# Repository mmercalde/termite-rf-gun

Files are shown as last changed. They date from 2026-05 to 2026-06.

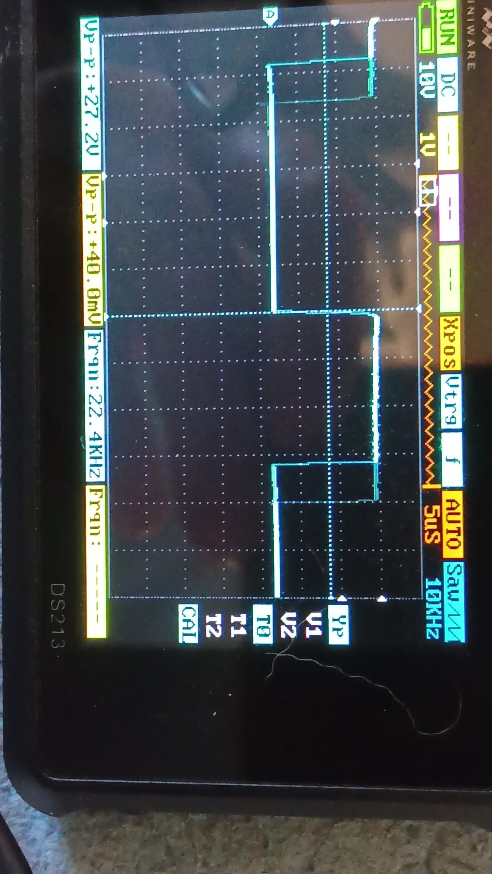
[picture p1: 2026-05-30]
docs/bench_observations/2026-05-30_frankenboard_dry_run_22kHz_DANGER.jpg

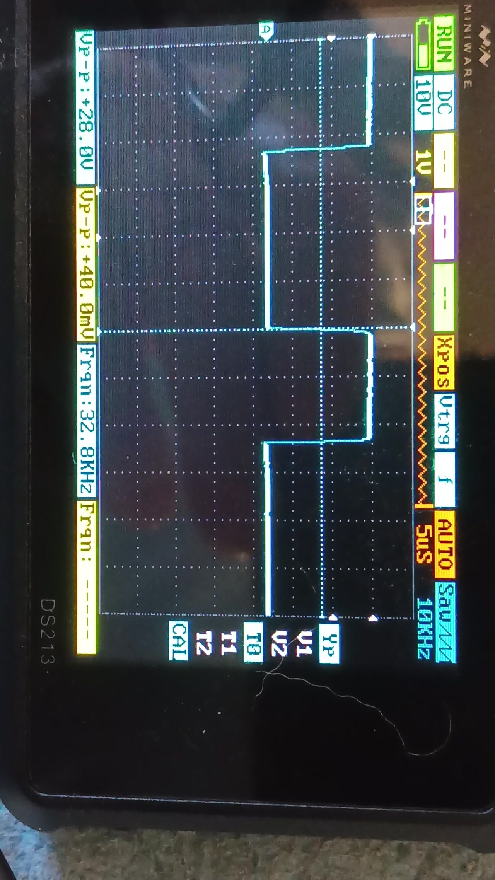
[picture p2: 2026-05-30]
docs/bench_observations/2026-05-30_frankenboard_dry_run_33kHz.jpg

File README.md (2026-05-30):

# termite-rf-gun

ESP32-S3 standalone driver for microwave inverter HV boards, powering an RF
applicator (launcher + copper-lined horn) for **termite control**. Goal: drive
a microwave inverter board with no oven main board (DPC), generating the HV the
magnetron needs, under ESP32 command.

Three inverter boards have been investigated. Status of each is below.

---

## Boards

### 1. Panasonic F606Y8X00AP — SINGLE-IGBT — ✅ SOLVED / PROVEN

The inverter board from a **Panasonic NN-SN778S** (120 V US oven).
Cross-references: replaces **F606Y8M00AP**; ABH-version variant is **F606Y9X90AP**
(this oven is the APH/USA version → F606Y8X00AP). Fits NN-SN7xx-series US ovens.

- **Driver: `panasonic_inverter_esp32s3/`** (tagged `working-standalone`)
- **Method that worked: CAPTURE & REPLICATE.** Built an ESP32 edge-logger
  (`log` mode, GPIO6 via divider off CN701 pin1), captured the real oven's
  command, then replicated it.
- **Measured command (the key result):**
  - **222 Hz** (period 4509 µs)
  - **~85 % HIGH duty**, idles HIGH, ~565–665 µs LOW notch
  - **NO soft-start** — full duty from cycle one; the inverter's own closed-loop
    current regulation handles magnetron inrush internally
  - **More HIGH duty = more power** (`INVERT_CMD=false` confirmed). The old
    "≤43 % duty to start" advice from a video was WRONG — under-driving gave
    "HV but no oscillation."
- Pin 3 (orange) tied to **1k → GND** sufficed on this board.
- **CONFIRMED WORKING** — magnetron oscillated under ESP32 drive.
- This board is borrowed from the kitchen oven. A twin (F606Y8X00AP) is the
  clean known-good path if the dual-IGBT effort stalls: runs on this firmware
  day one, no further tuning.

**Wiring (single-IGBT):**
```
GPIO4 -> CN701 pin1 (YELLOW)  command, push-pull TTL 222Hz/85%
GPIO5 -> CN701 pin3 (ORANGE)  optional 2nd signal (1k->GND also works)
GND   -> CN701 pin2 (BROWN)
GPIO7 <- zero-cross (monitor only)
GPIO6 <- capture tap (divider) for 'log' mode
GPIO1 = BTN ON/OFF ; GPIO2 = BTN power step
```

---

### 2. Panasonic F6645M301GP ("M3GP") — DUAL-IGBT — 🔧 TOPOLOGY PROVEN, TUNING PENDING

Dual-IGBT half-bridge board. **This is a 230–240 V board** (confirmed, see below).
Originally bought (×2) as a replacement for the NN-SN778S — that was a **mistake
on two axes**: wrong part family entirely (F606 vs F6645, single vs dual IGBT)
AND wrong voltage (230 V vs 120 V). Ironically these are the higher-power 240 V
boards that were actually wanted — accidentally the right thing.

- **Driver: `panasonic_dual_igbt_esp32s3/`**
- **Devices (original, both OBSOLETE):** big switch **Toshiba GT50J327**
  (intact); small switch **Toshiba GT35J321** (600 V / 35 A, the one that pops).
  Half-bridge topology.
- **Replacement IGBTs (Infineon TRENCHSTOP RC-H5, designed for inverterized
  microwave ovens / induction cooking, TO-247-3pin, monolithic body diode,
  8–60 kHz switching range):**
  - Big switch position → **IHW40N120R5** (1200 V / 40 A, BV min 1350 V)
  - Small switch position → **IHW30N120R5** (1200 V / 30 A, BV min 1350 V)
  - Voltage headroom on the small switch goes from 600 V → 1200 V, structurally
    eliminating the overvoltage-avalanche failure mode (candidate #3 below).
  - Bought 4× of each from Mouser → 4 rebuilds / tuning-casualty budget.
  - Keep ASYMMETRIC per Panasonic's original design (40 A big + 30 A small).
    Do NOT use 2× 30 A (big switch undersized at 30 A vs. resonant tank current)
    and do not "upgrade" to 2× 40 A on first attempt — it changes dead-time
    margin against shoot-through.
- **Controller IC:** Panasonic **AN47054A** class (undocumented). Runs closed-loop
  off DC-link / resonant-voltage / input-current sensing; generates the
  20–40 kHz IGBT gate switching itself. CN701 takes the LOW-FREQ ~220 Hz command,
  NOT the 20–40 kHz (that's an internal gate-drive frequency — common myth).
- **Resonant cap C703 = WF 395J 250V = 3.9 µF film**, sits IGBT-emitter to
  transformer primary. Measured 3.9 µF out of circuit → GOOD. (A resonant cap
  reads ~0 V at idle whether good or bad — only develops voltage during
  oscillation, so an idle 0 V reading is NOT a fault indicator.)
- Other caps: 505J/250V (~5 µF), WFK 184J/550V (180 nF across IGBT collectors).
  **No bulk electrolytic bus cap** — Panasonic design uses a small/unfiltered
  pulsating rectified rail by design.

**240 V CONFIRMATION (multiple independent sources):**
- Every parts listing cross-refs F6645M301GP to **230 V ovens**: NN-GT548M,
  NN-GD376S/GD576M, NN-GS, NN-K series (EU/Asia/Australia). No US 120 V model.
- Big IGBT GT50J327 = high-voltage Toshiba "J" series (now obsolete; replaced
  with IHW40N120R5 = 1200 V).
- Bridge rectifier = **D20SB80 = 800 V / 560 V RMS / 20 A** — built for a 230 V
  line (RMS ~240 V, peak ~340 V). A 120 V board would use a ~400 V bridge.
- At 120 V input → bus only ~163 V (measured) = half of the ~325–340 V it needs
  → under-voltage → "fires briefly then trips." Explains every earlier symptom.

**RESULT AT 240 V (the breakthrough):**
- Fed proper 240 V from the off-grid solar system (240 V double-breaker).
- Loaded `panasonic_dual_igbt_esp32s3`, typed `on` → **IT OSCILLATED.**
- This proves: 230 V board confirmed, command correct, feedback correct, board
  CAN run standalone on ESP32 drive.
- BUT after ~2–4 s: **POP** — the small IGBT (GT35J321) shorted.

**Why it popped (analysis — NOT simple thermal soak; it only ran 2–4 s on a
large heatsink):** more likely one of:
1. **Shoot-through** — half-bridge dead-time/timing off → both IGBTs briefly on
   → bus short through both → smallest device dies first. (µs-fast.)
2. **Over-current off-resonance** — resonant inverter; if driven off the tank's
   resonant point the IGBT current exceeds rating → fast junction failure.
3. **Overvoltage on the 600 V small IGBT** — at 340 V bus + resonant ringing, a
   transient can push the GT35J321 (only 600 V) past its limit → avalanche.
- All three trace to driving **open-loop** without the full closed-loop
  protection the AN47054A normally applies. The single-IGBT board tolerates
  open-loop because it's simpler; the dual half-bridge has shoot-through as a
  failure mode that only exists with two switches.
- NOTE: the two boards on hand had been **cross-swapped with parts between two
  damaged boards** (one had both IGBTs blown, the other a blown HV diode), so
  the board that popped was a hybrid of uncertain part health → its result is
  not fully trustworthy. → decision: buy NEW known-good boards to tune against.

**STATUS / NEXT (when new boards arrive):**
- Ordered new known-good F6645M301GP boards (AliExpress, "100% test working",
  ~$24.69 ea).
- Before firing a new board: set up a proper TUNING RIG —
  1. **Current limiting on the 240 V feed** (so a bad signal trips, not detonates
     the IGBT) — variac / resistive heater element / fast fuse.
  2. **Scope on the small IGBT gate (and/or its Vce)** — to SEE shoot-through
     (gate overlap) or overvoltage (Vce — with the new IHW30N120R5's 1200 V
     rating this is far less risky than with the original 600 V GT35J321, but
     still scope it) instead of tuning blind.
- Tuning procedure: start `p 40`, short 1–2 s bursts, watch gate scope + input
  current, dial up only when stable. Sweep feedback: try `sig2off` (free-run)
  vs the 110 Hz emulation, vary timing.
- Spares on hand: 4× **IHW30N120R5** (small position) + 4× **IHW40N120R5** (big
  position), Mouser, ~$5/ea. The original Toshiba GT35J321 / GT50J327 are
  obsolete and not worth sourcing — the Infineon RC-H5 parts are the modern
  replacement Infineon themselves market for inverterized microwave ovens.
  Casualties during tuning are expected; replacing one is a 10-min job.
- WHEN REPLACING A POPPED IGBT: also diode-check the partner IGBT AND the
  gate-driver components on that half-bridge leg BEFORE repowering — a shorted
  half-bridge IGBT often takes the driver/partner with it; powering into a
  damaged leg pops the new device instantly.

**Wiring (dual-IGBT):**
```
GPIO4 -> CN701 pin1 (YELLOW)        command, push-pull TTL 222Hz
GPIO5 -> 1k -> CN701 pin3 (ORANGE)  OPEN-DRAIN 110Hz/50% feedback emulation
GND   -> CN701 pin2 (BROWN)
GPIO7 <- zero-cross (monitor only)
```
Pin 3 is an open-collector line the board pulls to 5 V (measured 5 V HIGH on
start). GPIO5 only SINKS / releases (never sources). The 1k series protects the
non-5V-tolerant GPIO when it's released into the board's 5 V pull-up.

Console: `on` `off` `p<10-95>` `f<hz>` `ss <duty> <ms>` `sson` `ssoff`
`sig2on` `sig2off` `log` `logdump` `zc` `status`. Defaults: soft-start 35 %/2 s
→ ramp → 70 %, pin3 feedback ON, 222 Hz.

---

### 3. LG EBR82899411 / EBR82899402 — 🅿️ PARKED (revisit while waiting on dual boards)

Inverter from an **LG MSER2090S NeoChef** (120 VAC / 1200 W, magnetron 2M286-21).
Service manual: `mser2090s.pdf` (P/NO MFL69902612).

- **Architecture (per service manual + bench):** main board sends a command over
  **CN3** → the inverter's LOCAL hot-side MICOM **U1 (Renesas R5F1076C)** runs the
  closed loop and generates the 24–70 kHz IGBT switching itself. Same
  division of labor as the Panasonic (slow command in, fast switching local).
- **BLOCKER:** U1 stays **dead until mains is applied** — its 5 V/15 V bias derives
  from the rectified mains via the on-board regulator (U3). So the command path
  CANNOT be bench-tested on 15 V logic bias alone; U1 isn't running. This is the
  one structural difference from the Panasonic and why the LG is the hardest:
  it needs a **live-mains hot-side bring-up** before the command path is even
  testable, and then still needs a capture of CN3 to learn the command.

**CN3 pinout (bench-confirmed):**
```
Pin1 = U4 LED side via 10k (status opto, not our concern)
Pin2 = U4 LED other side (status, not our concern)
Pin3 = PWM cathode-side via on-board 330R to U2 LED cathode (drive LOW to enable)
Pin4 = PWM anode-side via on-board 330R to U2 LED anode (drive HIGH to enable)
Pin5 = key gap (unpopulated)
Pin6 = GND
Pin7 = +15V input
```
PWM control scheme: hold pin4 at +5 V, PWM pin3 (LOW = LED on = power).
F-11 test (svc man p5-26): CN3 pins 6–7 read OPEN(OL) normally; short = fault
(power-rail check, NOT a comms-pair check).

**Diagnostic IC values (svc man p5-27, ±10 % = OK):**
```
U1 MICOM (R5F1076C) pin2->GND = 15-20k ; pin10->GND = 4.5k
U6 gate driver (2EDL05I06PF, Infineon) = 1.0 Mohm
U7 op-amp (SN358) = 4.5k
U8 dual comparator (KIA393F) = 1.0 Mohm
TH91 thermistor ~20k @ room temp (F-16/17 if bad)
IGBT Q1: ~10k G-E ; C-E diode 0.4-0.6V
Bridge D5: open/short ; HV diodes D8,D9: open/short
```
Components: U1=RL78 MICOM, U2=PWM input opto, U3=onboard 5V reg, U4=status opto,
U6=Infineon half-bridge gate driver, U7=SN358 dual op-amp, U8=KIA393F dual comp,
Q1=IGBT, ZD201=trigger zener, TH91=B/D temp thermistor, D5=bridge, D8/D9=HV doubler.

**Bench results so far:** cold side draws 23 mA at 15 V idle; U3 outputs solid 5 V;
U2 LED conducts (5 mA bump) when pin4→5V AND pin3→GND (PWM input path functional).
U4 LED shows 1.16 V drop at idle (status output active). SPICE note: driving U2
via emitter-follower collapses to ~72 mV; open-collector (pull-up to 5V) gives a
proper 1.6–4.4 V swing, and response is INVERTED (higher duty = lower volts).

**NEXT for LG:** the only way forward is to confirm U1 wakes on mains. Plan:
(1) verify U2 phototransistor side crosses the isolation barrier (LED off vs on);
(2) live-mains hot-side power-up to bring U1 alive (DANGEROUS — mains-referenced
MICOM probing); (3) then capture CN3 during a real start to learn the command.
This is the most dangerous and least-certain path of the three — only worth it
as a "while waiting" exercise, with full mains-safety discipline.

---

## Firmware notes (shared)

- ESP32-S3 Dev Module, Arduino core 2.x/3.x, 4 MB, PSRAM off, USB CDC On Boot.
- Same ESP harness across all builds — only the command wire lands on a different
  connector/pin per board.
- `log` mode = capture an oven's real command on GPIO6 (via divider). This is the
  method that cracked the single-IGBT board and is the intended method for any
  board where a working oven is available to capture from.
- Serial 115200.

## Hard-won lessons

1. **Capture beats guessing.** The single-IGBT board was solved by capturing the
   real command, not theorizing. The dual board is hard precisely because there's
   no working dual-IGBT oven on hand to capture from.
2. **CN701/CN3 takes a LOW-FREQ (~220 Hz) command.** The 20–40 kHz is the IGBT
   gate switching the board generates internally — do NOT inject it into the
   command input.
3. **Input voltage first.** A 230 V board fed 120 V fires-then-dies on
   under-voltage. Check bridge rating (D20SB80=800V→230V) and bus voltage
   (163 V measured = half of needed) before chasing the command.
4. **An idle resonant cap reads ~0 V whether good or bad** — measure capacitance
   out of circuit, don't trust an in-circuit idle voltage.
5. **Don't tune on cross-swapped damaged boards** — parts that pass a DMM diode
   check can still be degraded under 340 V; use known-good boards for tuning so
   results are trustworthy.
6. **Dual half-bridge is less forgiving than single** — shoot-through is a
   failure mode that only exists with two switches; tune with current limiting
   and a gate scope.

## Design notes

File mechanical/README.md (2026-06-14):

# mechanical/

Parametric OpenSCAD for the 2.45 GHz applicator front end: magnetron cooling,
magnetron-to-launcher mounting, and the launcher seating recess. Target tube is
the U-Solution / LG **2M246** (front-view spec: 127 x 93.2 envelope, 80 body,
Ø36.5 center boss, Ø23 bore, 4-Ø4.5 holes at 114.3 / 95 c-c x 35 c-c).

## Parts

### magtube_fan_adapter.scad
60 mm fan (AFC0612D, 4-wire PWM) -> the magnetron's open face. The tube's own
steel side walls are the duct; this just adapts the round fan throat to the
open-face aperture.
- Inner opening **93 (long) x 57 (tall)**, with a **5 mm skirt** that wraps the
  collar (`flange_depth` / `flange_wall`).
- Round-to-rectangle transition up to a straight 60 mm fan collar so the four
  fan screws land on a flat, exposed face (`fan_collar`).
- Blow-through: fan in one open face, exhaust the opposite open face (the tube).

### magtube_mount_plate.scad
Magnetron-side mounting plate mirroring the 2M246 flange.
- Outline is Meshy's photo reconstruction, sectioned + scaled to 127 mm, with
  the four corner paddle wings.
- Dimensioned features: Ø23 bore, Ø36.5 center-boss seating relief, 8 wing holes
  on the 114.3 / 95 x 35 pattern.
- `relief_depth` **[SET]** = boss protrusion height (sets how far the antenna
  seats); measure on the real tube.

### launcher_magnetron_recess.scad
Launcher-side **negative** so the magnetron nests into the launcher instead of
sitting proud, with a gasket pocket and antenna bore.
- `part="cutter"` — Boolean-Difference into an existing launcher (top ref at Z=0).
- `part="mount"`  — standalone block with the recess pre-cut.
- **[SET]** `flange_recess` (steel flange thickness), `gasket_od`, `gasket_depth`.

## Render
```
xvfb-run -a openscad -o part.stl -D part='"all"' mechanical/<file>.scad
```

## Pending measurements (the only non-spec numbers)
- `relief_depth` / `flange_recess` — magnetron flange thickness + boss protrusion
- `gasket_od` / `gasket_depth` — RF choke gasket pocket
- collar-wrap skirt fit (`flange_depth` 5 mm, `flange_wall` 3 mm) — confirm on bench;
  may need the skirt relieved on the two short (57) sides if the flange/terminal
  end crowds that edge.

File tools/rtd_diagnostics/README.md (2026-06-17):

# RTD (MAX31865) diagnostic sketches

Standalone test sketches used during the 2026-06-15 MAX31865 bring-up.
See `docs/failure_analysis/2026-06-15_max31865_rtd_bringup_blocked.md` for the
full story. Each is self-contained; wire one MAX31865 board, flash, read serial.

Wiring (all three): VIN→3.3V (the VIN pin), GND→GND, CLK→GPIO11, SDO→GPIO13,
SDI→GPIO12, CS→GPIO1. PT100, RREF 430.

- `max31865_single_test`   [RTD-SOLO-v2] — one board, software SPI, sweeps 2/3/4-wire each second, flags the mode reading ~109 Ω.
- `max31865_hwspi_test`    [RTD-HW-v1]   — same, but driven by the ESP32-S3 hardware SPI peripheral (correct SPI mode).
- `max31865_manualcs_test` [RTD-MANCS-v1]— bare-register, MANUAL CS with an explicit CS-low→first-clock gap (the documented polarity-lock fix), plus a config write/read-back comms proof. **Run this first on a known-good ESP32** — its `comms test:` line settles board-vs-CS-timing.

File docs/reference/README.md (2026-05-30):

# Reference Documents

Archived primary sources for the Panasonic F6645M301GP inverter project,
stored locally so the project doesn't depend on external sites.

## Authoritative reference hierarchy

When references disagree, this is the order of authority:

1. **Michael's bench measurements on the actual board** — ground truth
2. **`Panasonic_ServiceCD_Schematic.png`** — Panasonic's own published schematic
3. **`Microwave_Oven_Inverter_HV_Power_Supply.pdf`** — VK3HZ writeup including
   the bench-measured behavior of the same topology
4. **`Panasonic_Inverter_Schematic_Annotated.pdf`** — community reverse-
   engineering, useful for additional component identification but may
   contain errors or refer to a different board generation

The Russian reverse-engineering was used as primary reference in earlier
revisions of the project docs. Subsequent corrections moved to the
Panasonic Service CD schematic as primary. Some early docs may still
reference Russian-schematic values that don't match the actual board —
fixes are ongoing as discrepancies are found.

## Files

### `Panasonic_ServiceCD_Schematic.png` (PRIMARY — Panasonic-authored)

Panasonic's own schematic of the HV inverter PSU, originally from the
Panasonic Service CD and reproduced in VK3HZ's writeup. Shows the dual-IGBT
half-bridge topology with full component-level detail except the controller
ASIC (drawn as a labeled black box).

**Component values from this schematic:**

| Ref | Value | Role |
|-----|---|---|
| L701 | (line choke) | Mains filter |
| DB701 | Bridged Diode | Mains rectifier |
| C702 | 4µF | DC bus filter (deliberately small per VK3HZ) |
| CT701 | Current Transformer | Input current sense |
| Q702 | (top IGBT) | High-side switch |
| Q701 | (bottom IGBT) | Low-side switch |
| R710, R711, R707 | 36Ω | Q702 gate resistor network |
| R712 | (small) | Part of Q702 gate network |
| ZD703, ZD704 | (zeners) | Q702 gate clamp |
| R713 | 11Ω | Q702 gate network |
| R714 | 11 1/2W | Q702 gate network |
| R708, R709 | 33kΩ each | Q702 gate bleed |
| R702 | 15kΩ | Sense divider top |
| R708 | 10kΩ | Sense divider bottom (listed twice — possibly two refs same value) |
| Q703 | (NPN) | Gate driver totem-pole NPN |
| Q704 | (PNP) | Gate driver totem-pole PNP |
| Q705 | (transistor) | Part of Q701 gate drive |
| R704 | 10Ω | Q701 gate inline resistor |
| R705 | 10kΩ | Q701 gate-emitter pulldown |
| D703 | (diode) | Sense/clamp |
| **C701** | **0.1µF** | **Across IGBTs (snubber + resonant element)** |
| **C703** | **0.45µF** | **Tank cap area** |
| C706 | 0.4µF | Tank cap |
| C706E | 0.4µF | Tank cap (separate reference) |
| T701 | Inverter HV Transformer | |
| P701, P702 | (primary terminals) | |
| S701, S702 | (secondary terminals) | |
| D701, D702 | UX-C2B (HV diodes) | HV doubler |
| **C704, C705** | **8200pF each** | **HV doubler caps** |
| R701 | 100MΩ | HV output bleeder |
| H701, H702 | — | Magnetron heater terminals |
| CN703 | HV output 4000V/300mA | To magnetron anode |

**CN701 (control connector) per Panasonic schematic:**
- **Pin 3**: Control signal INPUT (2-3V level) — command from DPC
- **Pin 2**: 0V (GND)
- **Pin 1**: Control signal OUTPUT (2-3V level) — status to DPC

This is the OPPOSITE pin labeling we'd been using in some docs. Michael's
physical wiring matches the Panasonic schematic (GPIO4 drives the inverter's
command input, GPIO5 reads the inverter's status output). Only the pin
*numbers* in some docs needed correction, not the actual circuit.

**Opto-isolators:**
- IC702 (with D706 in series, R733 = 1kΩ) = command opto (DPC → inverter)
- IC703 (with R732 = 11kΩ) = status opto (inverter → DPC)
- D706 is part of the command opto LED chain, NOT a separate status LED
  as the Russian schematic implied

**Controller ASIC** drawn as a single block with labeled functional sections:
- Power supply circuit low-voltage detect
- Power control
- Switching control
- Start control
- Feedback signal circuit

The internal pin numbering shown on the Russian schematic for the controller
IC was speculative — Panasonic doesn't publish ASIC internals.

### `Microwave_Oven_Inverter_HV_Power_Supply.pdf`

The canonical VK3HZ reverse-engineering writeup by David Smith VK3HZ
(vk3hz [at] wia.org.au). Includes the Panasonic Service CD schematic above
plus bench measurements, signal characterizations, and operational analysis.

Original URL:
http://www.vk3hz.net/amps/Microwave_Oven_Inverter_HV_Power_Supply.pdf

Mirrored at:
https://docplayer.net/21544207-Panasonic-microwave-oven-inverter-hv-power-supply.html

**Key facts established by VK3HZ via bench measurement** (not reverse-engineering):
- Control signal: 220 Hz square wave, variable duty cycle, TTL level (2-3V observed)
- Status signal: 110 Hz / 50% fixed, present when magnetron drawing current
- IGBT switching frequency: ~30 kHz internal
- 4 kV at 300 mA = 1200 W maximum output
- Constant-power regulation (1 W variation across 50% load change)
- 100 Hz ripple on HV from small C702 (4µF) — intentional design choice

### `Panasonic_Inverter_Schematic_Annotated.pdf`

Community-sourced reverse-engineering of a related Panasonic universal-input
inverter, with Russian and English functional-block annotations. Useful for:
- Confirming the controller ASIC's functional layout
- Additional discrete component identification
- Cross-reference for board generations

**Known discrepancies with the Panasonic Service CD schematic:**
- C701 listed as 0.68µF / 500V (Panasonic schematic shows 0.1µF)
- Q703 designated NPN with specific 2SC2785 part number (Panasonic schematic
  shows generic transistor symbols, exact P/N not specified)
- May reflect a different board generation or contain reverse-engineering errors

Use this as supplementary reference only when the Panasonic schematic doesn't
provide enough detail.

## F6645M301GP-specific deltas (Michael's actual board)

The board in this project is a specific revision with values that differ
from the generic Panasonic Service CD schematic:

| Ref | Service CD schematic | Michael's actual board | Source |
|-----|---|---|---|
| C701 | 0.1µF | **0.18µF / 500V** (WFK 184J) | Photo, confirmed |
| C704 | 8200pF | 8200pF (DHC 822J 3000V) | Photo, confirmed |
| C705 | 8200pF | **5600pF** (DHC 562J 3000V) | Photo — asymmetric on this board! |
| R702 | 15kΩ | **3.5kΩ 15W** (RYC-3 3K5J) | Photo, confirmed |
| R701 | 100MΩ | 100MΩ (OL on meter) | Bench, confirmed |
| Q701 | (TO-247 IGBT) | IHW40N120R5 (Infineon TRENCHSTOP RC-H5) | Replacement choice |
| Q702 | (TO-247 IGBT) | IHW30N120R5 (Infineon TRENCHSTOP RC-H5) | Replacement choice |

The asymmetric HV doubler caps (8.2nF + 5.6nF) and different resonant cap
value (0.18µF vs 0.1µF) indicate this is a later revision than the schematic
documented. These differences shift the resonant frequency slightly from
what the generic schematic would predict.

## Attribution

The Panasonic Service CD schematic is Panasonic's intellectual property,
reproduced here under fair-use reference for repair purposes (the equipment
is past its commercial service life). VK3HZ's analysis text is copyright
David Smith VK3HZ. The Russian reverse-engineering source is unknown.

Cite original sources in any publication or derivative work.

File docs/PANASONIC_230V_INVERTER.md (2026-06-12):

# Panasonic 230V Dual-IGBT Inverter — Reference Notes

Project board: **F6645M301GP** (and related: F6645M300GP, F6645M303GP,
F6645M305GP, F6645M306GP, F6645M302BP). Closely related family with shared
architecture: **F606YM300BP** (NN-ST657S etc.) and **A606YM30** (Hungarian
forum references). All are 230V dual-IGBT half-bridge inverters from
Panasonic Home Appliances Microwave Oven (Shanghai) Co., Ltd., circa 2006-2010.

This document captures what we know about these boards from publicly
available sources, since Panasonic deliberately does not publish inverter
schematics in service manuals (treated as non-serviceable subassemblies).

---

## Why no FCC schematic exists

FCC certification is **US-market only**, and the US is 120V. Every Panasonic
inverter board in the FCC schematic database is therefore a **120V
single-IGBT** design. The closest public document (FCC ID ACLAP4T01,
single-IGBT NNS540/NNS560-era) shows the analog ASIC (IC801) controller
architecture but not the dual-IGBT topology.

230V dual-IGBT boards never go through FCC certification because they're
not sold in the US. The European/Asian regulatory paths (CE, VDE, BSI,
IEC, CCC) do not require public schematic disclosure.

**Conclusion:** there is no *official Panasonic-published* schematic for
F6645M301GP specifically, but two schematics of similar dual-IGBT inverter
generations are archived in the repo:

1. **PRIMARY: `docs/reference/Panasonic_ServiceCD_Schematic.png`** — taken
   from the Panasonic Service CD (via VK3HZ's PDF). Shows full component
   detail except the proprietary controller ASIC. This is the authoritative
   reference.

2. **Supplementary: `docs/reference/Panasonic_Inverter_Schematic_Annotated.pdf`** —
   community reverse-engineering of a universal-input variant. Useful for
   cross-reference but contains some errors relative to the Panasonic
   schematic. Use only when the Panasonic schematic doesn't provide enough
   detail.

Both show the same dual-IGBT half-bridge topology as F6645M301GP. See the
[Component values](#component-values--panasonic-service-cd-schematic--bench-measurements)
section below.

---

## What's actually in the public service manuals

### NN-ST657S / NN-ST677M / NN-ST667W / NN-ST657W (2007, Australia/NZ 230V)

Service manual order number PHAMOS0706032A3. The closest published Panasonic
service document to our F6645M301GP. Inverter board is **F606YM300BP** —
dual-IGBT, same architectural family.

- Browser viewer: https://www.manualslib.com/manual/1871563/Panasonic-Nn-St657s.html
- Page 5: oven-level schematic only (inverter shown as black box)
- Page 14: semiconductor ohmmeter check table + inverter parts list
- The inverter internal schematic is **NOT included** in the manual

### F606YM300BP main parts list (from NN-ST657S page 14)

| Ref | Part No. | Description | Notes |
|-----|---|---|---|
| **Q701** | A691EM300BP | IGBT | Main switch (big) |
| **Q702** | *(blank)* | IGBT | Smaller switch — no Panasonic P/N |
| **C701** | ECWF5184N300 | Film capacitor | **Resonant tank cap — critical** |
| C702 | ECQE2505T869 | Film capacitor | DC bus / snubber |
| C703 | ECWF2395N632 | Film capacitor | |
| DB701 | B0FBBS000001 | Rectifier bridge | Mains bridge |
| L701 | F5020M300GP | Choke coil | Mains filter |
| R702 | D0CM352JA002 | Sand bar resistor | 15W wirewound |
| **T701** | A609AM300GP | Transformer assembly | **Includes D701, D702, C706, C707** — HV doubler built into transformer assy, not separately replaceable |
| D701, D702 | B0FBAZ000001 | HV diodes | Part of T701 assembly |
| C706, C707 | ECWH3xxx | HV film caps | Part of T701 assembly |

### Semiconductor ohmmeter test table (NN-ST657S page 14)

For testing the IGBTs in or out of circuit:

| Pin pair | Forward (red→first listed) | Reverse |
|---|---|---|
| E–C | SMALL (body diode 0.4-0.7V) | ∞ |
| E–G | ∞ | ∞ |
| C–G | ∞ | ∞ |

Use this to verify new IGBTs before installation and to test suspected
damage on existing boards.

---

## Component values — Panasonic Service CD schematic + bench measurements

**Primary reference:** `docs/reference/Panasonic_ServiceCD_Schematic.png`
(Panasonic's own schematic from the Panasonic Service CD, reproduced in
VK3HZ's writeup). This supersedes the Russian community reverse-engineering
which contained some errors.

### Half-bridge IGBT topology

The schematic confirms **dual-IGBT half-bridge** architecture:

- **Q702** (top IGBT, high-side switch)
  - Gate driven through R710 + R711 + R707 (36Ω each) + R712 + R713 (11Ω) +
    R714 (11Ω 1/2W) + ZD703, ZD704 clamps
  - R708, R709 (33kΩ each) as gate bleed/clamp
  - Elaborate gate drive because high-side requires level-shifting
- **Q701** (bottom IGBT, low-side switch)
  - Gate driven by Q703/Q704/Q705 totem-pole (NPN/PNP/NPN complementary pair)
  - R704 (10Ω) inline gate resistor
  - R705 (10kΩ) gate-emitter pulldown
  - Simpler gate drive because it's ground-referenced

The asymmetric gate drive networks (more complex for Q702, simpler for Q701)
are why Panasonic uses asymmetric IGBT current ratings — high-side and
low-side see different di/dt and dv/dt stress.

### Component values from Panasonic Service CD schematic

| Ref | Value | Role |
|-----|---|---|
| L701 | (line choke) | Mains filter |
| DB701 | Bridged Diode | Mains rectifier |
| C702 | 4 µF | DC bus filter (deliberately small per VK3HZ) |
| CT701 | Current transformer | Input current sense → constant-power loop |
| R702 | 15 kΩ | Sense divider |
| R708 (one occurrence) | 10 kΩ | Sense divider |
| R704 | 10 Ω | Q701 gate inline resistor |
| R705 | 10 kΩ | Q701 gate-emitter pulldown |
| R707, R710, R711 | 36 Ω each | Q702 gate resistor network |
| R713, R714 | 11 Ω each | Q702 gate network |
| R708, R709 | 33 kΩ each | Q702 gate bleed |
| C701 | 0.1 µF | Across IGBTs (snubber/resonant) |
| C703 | 0.45 µF | Tank cap area |
| C706, C706E | 0.4 µF each | Tank cap |
| ZD703, ZD704 | (zeners) | Q702 gate clamp |
| D703 | (diode) | Sense/clamp |
| T701 | HV transformer | Step-up + bias winding |
| D701, D702 | UX-C2B (HV diodes) | HV doubler |
| C704, C705 | 8200 pF each | HV doubler caps (schematic value) |
| R701 | 100 MΩ | HV output bleeder |
| CN703 | HV output 4000V/300mA | To magnetron anode |
| H701, H702 | — | Magnetron heater terminals |
| IC702 + D706 + R733 (1 kΩ) | Command opto | DPC → inverter |
| IC703 + R732 (11 kΩ) | Status opto | Inverter → DPC |

### F6645M301GP-specific deltas — Michael's actual board

Several component values on Michael's specific board differ from the
generic Panasonic Service CD schematic. These are documented in detail in
`docs/reference/README.md`. Summary:

| Ref | Schematic value | Michael's board | Status |
|-----|---|---|---|
| C701 | 0.1 µF | **0.18 µF** (WFK 184J 500V) | Photo confirmed |
| C704 | 8200 pF | 8200 pF (DHC 822J 3000V) | Photo confirmed |
| C705 | 8200 pF | **5600 pF** (DHC 562J 3000V) | Photo confirmed — asymmetric |
| R702 | 15 kΩ | **3.5 kΩ 15W** (RYC-3 3K5J) | Photo confirmed |
| R701 | 100 MΩ | 100 MΩ (OL on meter) | Bench confirmed |
| Q701 | (TO-247 IGBT) | IHW40N120R5 | Infineon replacement |
| Q702 | (TO-247 IGBT) | IHW30N120R5 | Infineon replacement |

The asymmetric HV doubler caps and different C701 value indicate this is
a later revision than the schematic documented.

### Note on Russian reverse-engineering

The earlier-archived `Panasonic_Inverter_Schematic_Annotated.pdf` (Russian
community reverse-engineering) was used as primary reference in initial
project work. It contains some errors relative to the Panasonic Service CD
schematic:
- Q701/Q702 values for resonant cap shown as 0.68 µF (Panasonic says 0.1 µF;
  Michael's board has 0.18 µF — closer to Panasonic)
- Specific part numbers (C2785 NPN, A1174 PNP) for gate drivers were
  speculative; Panasonic shows generic transistor symbols
- Controller IC pin numbering (2-15) shown was speculative

Use the Russian schematic only as a supplementary reference. When values
disagree, trust the Panasonic Service CD schematic.

### Controller IC functional blocks

The custom Panasonic analog ASIC (no public part number for the dual-IGBT
generation) handles these functions, labeled in the schematic:

1. **Power supply circuit low-voltage detect** (pins 2, 3, 5, 6) —
   monitors mains/DC bus, prevents operation below threshold (this
   is what caused trouble during 120V testing of the 230V boards)
2. **Power control** (pins 7, 8) — accepts the duty-cycle command
3. **Switching control** (pins 9, 15, 13, 4) — generates internal 24-40 kHz
   IGBT drive signals
4. **Feedback signal circuit** — receives current/voltage sense, drives
   the constant-power regulation loop
5. **Start control** (pins 10, 11, 12) — handles the cold-start sequence
   and decides when to assert the 110 Hz status signal
6. **CN701 interface** (pins 14, 13, 1, 4 → IC701/IC702 optos) — opto-
   isolated boundary to the DPC

---

## CN701 interface

3-pin connector from inverter board to Digital Programmer Circuit (DPC).

**Pin roles per the Panasonic Service CD schematic:**

| Pin (Panasonic schematic) | Role | Driven by | Signal |
|---|---|---|---|
| 3 | Command (input to inverter) | DPC (or our ESP32) | 220-222 Hz square wave, variable duty = power setpoint, 2-3V level |
| 2 | 0V (GND) | Common | Opto-isolated ground reference |
| 1 | Status (output from inverter) | **Inverter ASIC** | 110 Hz / 50% square wave, present only when magnetron is drawing current, 2-3V level |

**Note on pin numbering vs wire colors:**

Earlier project documentation used a different pin numbering convention
(swapping pin 1 and pin 3 labels). The *physical wiring* on Michael's
build matches the Panasonic schematic correctly — GPIO4 drives the
inverter's command input, GPIO5 reads the inverter's status output.
Only the numerical labels in some docs needed correction; no physical
rewiring is required.

The colors-to-roles mapping on Michael's actual cable:
- **Yellow** wire = command (GPIO4 → inverter command input)
- **Brown** wire = GND (common)
- **Orange** wire = status (inverter status output → GPIO5)

If documentation elsewhere in this repo refers to "pin 1 = command" or
"pin 3 = status," that's the older convention. The Panasonic schematic
is authoritative going forward.

**Critical:** the status line (orange, GPIO5) is INPUT to the ESP32.
The inverter generates the 110 Hz status signal internally; our firmware
must NOT drive this line — it must read it. The previous firmware
revision (before commit `3128125`) drove this line, which corrupted the
inverter's internal feedback loop and contributed to IGBT failure. See
`VK3HZ_FINDINGS.md` for the startup-sequence implications.

---

## Service-manual sources for related Panasonic dual-IGBT boards

These can all be downloaded from ManualsLib (free, may want signup) or
elektrotanya. None contains the actual inverter schematic, but several
have useful test procedures, troubleshooting flows, and parts data.

| Manual | Models | Inverter board | Pages | Notes |
|---|---|---|---|---|
| NN-ST657S service | ST657S/ST677M/ST667W/ST657W | F606YM300BP | 27 | Best reference for F6645M family (supplement to NN-S560WF). [Link](https://www.manualslib.com/manual/1871563/Panasonic-Nn-St657s.html) |
| NN-ST678S service | ST678S | similar | 40 | Full standalone manual |
| NN-ST681S service | ST681S | similar | 42 | Full standalone manual |
| NN-SD697S service | SD697S | similar | 35 | |
| NN-SD698S service | SD698S | similar | 40 | |
| NN-GD376S service | GD376S/GD366M/GD356W | F606YM300BP | 31 | Microwave/grill, 2006. [Link](https://www.manualslib.com/manual/801129/Panasonic-Nn-Gd376s.html) |
| NN-SD798S service | SD798S | F606Y8M00AP (single-IGBT) | — | LATIN AMERICA 120V variant. Architecture-similar, single-IGBT. [Direct PDF](https://www.csportal.panasonic-la.com/DESCARGASPLA/PLA/ELECTRODO/MICROONDAS/INVERTER/NN-SD798SRPH/MANUAL%20DE%20SERVICIO/sd798s_rph.pdf) |

---

## Reference / community sources

**VK3HZ reverse-engineering** (canonical, captured in `VK3HZ_FINDINGS.md`):
- http://www.vk3hz.net/amps/Microwave_Oven_Inverter_HV_Power_Supply.pdf
- Docplayer mirror (browser-viewable): https://docplayer.net/21544207-Panasonic-microwave-oven-inverter-hv-power-supply.html

**FCC schematics (120V single-IGBT only — for architectural reference):**
- ACLAP4T01 (NNS540/NNS560): https://fccid.io/ACLAP4T01/Schematics/Inverter-Power-Supply-Schematic-77643
- ACLAP7A01 (NN-P994SFR, 2007): https://fccid.io/ACLAP7A01 — confirmed single-IGBT
- ACLAP5H01: https://fccid.io/ACLAP5H01 — older single-IGBT
- ACLAPCB01 (NN-GN68KS, 2019): https://fccid.io/ACLAPCB01 — modern single-IGBT

**YouTube reverse-engineering:**
- tomtechtod9200 F66459X91AP H97 inverter (sister board to ours):
  https://www.youtube.com/watch?v=LZb6v0JMOuU
  Note: this video confirms 220 Hz command signal and lists related boards
  (F606Y8X00AP, F606YM300BP, F606Y6G00CP, F606Y8X04AP) as sharing the same
  architecture.

**Forum threads:**
- Hungarian elektrotanya — F606YM30 / F6645 IGBT replacement discussion
  (mentions GT35J321 + GT50N322 originals): https://elektrotanya.com/panasonic_microwave_inverter.pdf/download.html
- High Voltage Forum repair thread:
  https://highvoltageforum.net/index.php?topic=1639.0
- Fusor.net thread (fusion enthusiasts using these as HV supplies):
  https://fusor.net/board/viewtopic.php?t=4820
- AllAboutCircuits inverter-microwave-oven thread:
  https://forum.allaboutcircuits.com/threads/inverter-microwave-ovens.143728/

**LG patent (alternate-architecture reference, not Panasonic):**
- US6936803B2, US7064306B2 — LG dual-IGBT inverter patents, useful for
  understanding the closed-loop current regulation pattern common across
  the consumer inverter industry.

---

## Original IGBTs in F6645M301GP

| Position | Toshiba Original | Class | Status |
|---|---|---|---|
| Q701 (big) | GT50J327 | 600V, 50A, 4th-gen, current-resonance inverter family | Obsolete |
| Q702 (small) | GT35J321 | 600V, 35A, current-resonance inverter family | Obsolete |

Both Toshiba parts are obsolete and not stocked at mainline distributors
(Mouser, Digi-Key). Replacements must be either pulled from donor boards
or substituted with modern equivalents.

## Infineon TRENCHSTOP RC-H5 replacements (Mouser-stocked, current production)

| Position | Replacement | Class | Notes |
|---|---|---|---|
| Q701 (big) | **IHW40N120R5** | 1200V, 40A nominal (80A pulse), TO-247 | https://www.infineon.com/part/IHW40N120R5 |
| Q702 (small) | **IHW30N120R5** | 1200V, 30A nominal (60A pulse), TO-247 | Smaller die from same family |

### Parameter comparison (Toshiba originals vs. Infineon replacements)

| Parameter | GT50J327 | IHW40N120R5 | GT35J321 | IHW30N120R5 |
|---|---|---|---|---|
| VCES (max) | 600 V | **1200 V** (2× headroom) | 600 V | **1200 V** |
| IC continuous | 50 A | 40 A nominal (80 A peak) | 35 A | 30 A nominal (60 A peak) |
| VCE(sat) typ | 2.1 V | **1.55 V** (lower loss) | 2.0 V | 1.55 V |
| Fall time tf | 250-300 ns | **20 ns** (10× faster) | ~250 ns | ~20 ns |
| Gate threshold | ~5-6 V | 5.8 V | ~5-6 V | ~5.8 V |
| Body diode | Yes, integrated FRD | Yes, monolithic | Yes | Yes |
| Tj(max) | 150°C | 175°C | 150°C | 175°C |
| Package | TO-247 | TO-247 | TO-247 | TO-247 |
| Pinout | G-C-E | G-C-E | G-C-E | G-C-E |
| Family | "Current Resonance Inverter Switching" | "Resonant Switching RC-H5" | Same | Same |

The Infineon parts are the right family for this application
(resonant-switching inverters, not motor drives), drop-in mechanically,
and have substantial headroom in every direction (V, I, T). The only
meaningful behavioral difference is faster switching (~10× faster fall
time), which is generally beneficial but could in some cases warrant a
small gate resistor (5-22Ω series) to dampen edge ringing.

---

## Failure modes observed on these boards (literature + our experience)

1. **Both IGBTs blown** — most common failure. Almost always cascades
   bridge rectifier and/or gate driver components. Treat board as
   suspect even after IGBT replacement.
2. **HV diode in T701 shorted** — kills magnetron oscillation, can stress
   IGBTs. Cannot replace separately, must replace whole T701 assembly.
3. **C701 (resonant cap) degraded** — silent killer. Shifts resonant
   frequency, makes inverter off-resonance, destroys new IGBTs almost
   immediately. Always measure capacitance and ESR on suspect boards.
4. **R702 (sand-bar 15W) drift open** — bias/clamp resistor, hot in
   normal operation, prone to drift after years of use.
5. **DB701 bridge rectifier shorted** — sometimes primary failure,
   sometimes downstream from IGBT short-circuit event.

## Panasonic service-bulletin precedent for IGBT upgrades

Per VK3HZ findings, Panasonic themselves issued an IGBT upgrade kit for
the single-IGBT NN-S550WF family. The kit replaced:
- Q701: GT60N90 (900V) → **GT60N321 (1000V)** — higher voltage class
- Plus a control-board capacitor change: **330 pF → 56 pF**

This proves three things relevant to us:
1. The original IGBTs were marginal even by Panasonic's standards
2. Upgrading to higher voltage class is a valid factory-approved approach
3. Gate-timing capacitor tuning may need to follow IGBT speed changes
   (worth keeping in mind if our 10×-faster Infineon parts cause issues)

---

## What we still do NOT have

- Actual Panasonic-issued schematic of F6645M301GP specifically (closest
  is the community-reverse-engineered universal-input schematic now
  archived in `docs/reference/`)
- Schematic of the IC801-equivalent controller IC on the dual-IGBT
  generation (the functional blocks are labeled but the internal die
  is proprietary)
- Specific F6645M301GP resonant tank operating frequency (estimated
  24-40 kHz per LG patents and VK3HZ universal-input data, but exact
  frequency unconfirmed for our boards)
- Definitive part number for Q702 in F606YM300BP parts list (Panasonic
  left it blank in their own documentation)
- Snubber component values for the 230V variant specifically

These would have to be reverse-engineered from a known-good physical
board if we ever need definitive answers.

---

## VR701 / VR1 — current-sense calibration trim (topology is generation-dependent)

**Bottom line:** VR701 is the factory power-calibration trim — bench-confirmed
on Michael's board (50k "503"). It scales a current-sense signal into the
controller IC; it is NOT a filament adjust.

**IMPORTANT CORRECTION (2026-06-12):** the sense *topology* is generation-
dependent and the earlier "no CT701 / it's a SHUNT R703" claim in this section
overstated what's actually documented. The record now:

- **Both schematics IN THIS REPO show a CURRENT TRANSFORMER (CT701)**, not a
  shunt, in the AC line between CN702 and the bridge rectifier DB701:
  - `Panasonic_ServiceCD_Schematic.png` (authority #2) — labels it explicitly
    "CT701 / CURRENT TRANSFORMER".
  - `Panasonic_Inverter_Schematic_Annotated.pdf` (Russian RE, authority #4) —
    also shows CT701 (secondary -> R715 4.5K/15W -> R716/R717 100R -> VR701/R719
    divider -> controller power-control pins 7/8). Note Russian shows VR701=1k,
    not 50k.
- **Michael's ACTUAL board has NO current transformer** — confirmed by visual
  inspection — and uses a **resistor-network sense instead.** This is consistent
  with it being a LATER REVISION (same board already shows later-gen deltas:
  0.18uF resonant cap, asymmetric 8.2nF/5.6nF doubler, 3.5K R702). Panasonic
  migrated this sense path from CT to a resistor network on newer boards.
- So: "CT701" is correct for the documented (older) generation; "resistor
  network, no transformer" is correct for Michael's (later) board. Both are
  true for their respective generations.

### What the part is
- Board silkscreen **VR1** = schematic **VR701**. White trimmer marked **"503"
  = 50 kOhm** (photo-confirmed, component side). Note this is a third value in
  the family: V-series doc = 1k, L/N-series doc = 10k, this board = 50k.
- Physical location: cold/control side, between CN702 (above) and CN701
  (below), in the small-signal cluster near the IC702/IC703 optos.
- Panasonic flags it **"DO NOT ADJUST VR701"** — see the annotated board photo
  on **page 7 of the NN-GD376S service manual** (manualslib id 801129). That
  photo is the best physical-location reference we have for VR701, better than
  either schematic. The "do not adjust" warning has one documented exception:
  adjustment IS required after the HV transformer (T701) is replaced.

### Sense topology on Michael's board — resistor network (NOT schematic-backed in repo)
Michael's board uses a **resistor-network current sense, no current transformer**
(visual inspection). Earlier revisions of this doc called the element "SHUNT R703
in the DC-bus return," citing the **tomtechtod9200 RE schematic** — but that
schematic is **NOT in this repo**, and the **two schematics that ARE in the repo
both show CT701** (see correction above). So the specific "R703, DC-bus return"
designation and location is **board-observed + external-RE inferred, NOT verified
against any in-repo schematic.** Treat the *resistor-network* fact as solid (seen
on the board); treat the *exact element ID, value, and tap point* as UNCONFIRMED
until the board trace below is done. VR701 scales whatever this network produces
before it reaches the controller.

### Controller IC
Named on the RE schematic as **AN47054A** (Panasonic analog ASIC, no public
datasheet). Its internal regulation behaviour is unknown; we model only the
passive front-end feeding it.

### Sense chain (as read; assumptions flagged)
    SHUNT R703 -> front-end -> Vsense
    Vsense --[2k4]-- nIn --[R40 (value TBC)]-- potHi
    VR701 50k:  potHi --(1-p)*50k-- wiper --(p)*50k-- GND
    wiper --[100k]-- controller sense pin (~pin 13)

### SPICE result (script NOT in repo — treat as hypothesis, not verified)
NOTE (2026-06-12): `spice/vr701_cal.py` and `spice/results/03_vr701_cal.png`
are CITED here but are **NOT present in the repo** (only `spice/ngspice_sweep.py`,
a tank frequency sweep, exists). The conclusions below were never reproducible
from committed files — treat them as a reasonable first-principles HYPOTHESIS to
confirm on the bench, not a verified simulation. Also: the model assumed a
specific sense front-end whose topology is now in question (see correction above),
so even the qualitative result needs re-checking against the real board network.
- Voltage at the controller sense pin is **linear** in wiper position ->
  VR701 is a linear gain control on the current-sense signal.
- If the chip regulates that pin to a fixed reference, the regulated current
  (= power) setpoint is a **1/x** curve vs VR701:
  - **more wiper -> chip reads more volts/amp -> backs off -> LOWER power**
  - **less wiper -> under-reads -> pushes harder -> HIGHER power**
- **Danger zone = low-wiper / high-power end** (curve is steep there; small
  moves swing current hard -> IGBT avalanche risk). High-wiper end is flat
  (fine, safe low-power control).
- Shape is robust to the unknowns; absolute numbers are NOT.

### Calibration procedure (after identical-T701 swap)
1. Mark the original wiper position before touching it. Identical part -> only
   tolerance moves -> expect a small tweak, not a full recal.
2. If disturbed/unknown: set to the LOW-power end first, power up at low DPC
   duty, confirm screwdriver direction vs power on the inline ammeter, then
   bring power UP slowly toward your target current. Small nudges near max.
3. Target = YOUR load's intended operating current at your chosen duty, NOT the
   oven's spec'd input current (meaningless for this application).

### Open items for bench confirmation
- **RESOLVING MEASUREMENT (do this first): trace VR701's wiper and both ends.**
  This single trace settles the whole topology question that neither in-repo
  schematic answers for this board:
  - If the sense input originates at a **low-value resistor in the rectified-DC
    return** -> shunt/resistor-network, bus-referenced (probing hazard; needs
    isolation to read).
  - If it originates at a **transformer/toroid in the AC line** (where CT701 sits
    on the schematics) -> CT-coupled and isolated after all.
  Result determines (a) shunt vs divider topology, (b) whether it's bus-
  referenced (safety), (c) which VR701 calibration physics actually applies.
- R40 actual value (if a resistor network), and VR701 wiring (divider vs
  rheostat; where the wiper truly returns).
- Whether the controller regulates this pin to a fixed reference, and its value.
- One real datapoint: measured input current at a known VR701 position + DPC
  duty, to pin the curve's absolute scale (also serves as the IGBT-current
  visibility the sweep firmware lacks).

- 2026-06-12 CORRECTED the VR701/sense section after reading both in-repo
  schematics directly. Both `Panasonic_ServiceCD_Schematic.png` (Panasonic,
  authority #2) and `Panasonic_Inverter_Schematic_Annotated.pdf` (Russian RE,
  #4) show **CT701 CURRENT TRANSFORMER** in the AC line — NOT a shunt. The
  earlier "no CT701 / SHUNT R703 in DC-bus return" claim is board-observed +
  external-RE (tomtechtod9200, not in repo) and is NOT backed by any in-repo
  schematic. Re-framed as: CT701 = documented/older generation; resistor-network
  (no transformer) = Michael's later board, confirmed only by visual inspection,
  exact element ID/value/tap point UNCONFIRMED. Flagged `spice/vr701_cal.py` as
  missing from repo (conclusions = hypothesis, not verified). Promoted "trace
  VR701 wiper + both ends" to the top resolving measurement.

## Earlier document history

- 2026-05-30 Initial creation, gathered after IGBT failures on
  Frankenboard built from two damaged donor boards.
- 2026-05-30 Added archived community schematic reference (universal-input
  dual-IGBT), extracted component values and gate-drive topology details.
  Confirmed both Q701 and Q702 are power IGBTs in half-bridge configuration.
- 2026-05-30 Switched primary reference from Russian community schematic to
  Panasonic Service CD schematic (more authoritative). Corrected CN701 pin
  numbering to match Panasonic's convention (pin 3 = command IN, pin 1 =
  status OUT). Noted physical wiring is correct per Panasonic schematic;
  only numerical labels in earlier docs were swapped. Added F6645M301GP-
  specific component value deltas observed via board photos.

- 2026-06-07 Added VR701/VR1 section. CORRECTED: no CT701 on these boards;
  current sense is SHUNT R703 (DC-bus return). VR701 = 50k "503" trimmer =
  current-sense GAIN calibration into AN47054A controller (named from RE
  schematic). Added SPICE model (spice/vr701_cal.py) showing linear sense gain
  -> 1/x power setpoint, polarity (more wiper = lower power), danger at
  low-wiper/high-power end. Added NN-GD376S p.7 annotated photo as VR701
  physical-location reference. Superseded earlier CT701-based loop description.

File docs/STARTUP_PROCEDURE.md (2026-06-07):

# Verified Startup Procedure (AUTHORITATIVE)

Canonical, bench-proven startup for driving the Panasonic 2-IGBT inverter
(F6645M301GP) standalone from the ESP32-S3. Source of truth: firmware build
**FBLOW-RETRY-v5** in `panasonic_dual_igbt_esp32s3.ino`, developed in the
"New Panasonic boards arrival" session (2026-06-06).

This supersedes any "send a higher-duty warm-up burst then drop to the requested
level" framing, which described the OEM DPC's *low-power cycling* behaviour and
is NOT how we drive the board.

## Provenance — the cross-install experiment ("the bible")

The command *protocol* was captured from the OEM controller itself, under the
cleanest possible conditions:

- A **230V inverter** installed into a **120V microwave**.
- 230V inverter fed from its **own 230V supply**; 120V control fed from its
  **own 120V supply**.
- The **only** link between domains was **CN701**.
- The 120V control board **fired the tube** in the 230V inverter.

That proves the CN701 command protocol transfers and the 230V inverter responds
to it. Capture (`captures/oven_run1.txt`, parsed): **221.8 Hz** (period 4509 us),
asymmetric ~565 us / ~3944 us split, active-high (`INVERT_CMD = false`), no
soft-start.

**What the cross-install does and does NOT establish:** it is authoritative for
the *protocol* — 222 Hz, polarity, pin roles. It is NOT authoritative for run
*duty magnitude*: the 120V controller's command (~85% high) is calibrated for
120V operation and does NOT port to the 240V board. Duty is not voltage-portable
on a constant-power inverter (120V needs more on-time to reach a given power,
240V less). The 240V duty values come from our own working build (below), not
from the 120V capture.

## The verified startup sequence — FBLOW-RETRY-v5

Status-gated: never commits to continuous drive until the inverter confirms the
tube has struck.

1. **Startup / filament warm-up pulse.** Drive **222 Hz at 33% duty** on
   **CN701 pin 3** for a **2500 ms** attempt window.
2. **Watch feedback, CN701 pin 1**, with a **3-consecutive-reads glitch guard**
   (the RF field near the firing magnetron injects ~870k glitches/s into bare
   GPIOs; the guard rejects them):
   - **Pin 1 goes (and stays) LOW** = inverter is drawing current = **tube
     struck.** -> go to step 4.
   - **Pin 1 stays HIGH** = not struck yet (filament not hot enough). -> step 3.
3. **Retry.** Stop, wait a **1500 ms restart gap**, repeat the 2500 ms / 33%
   attempt. **Up to 8 retries.** This 2500-on / 1500-off rhythm matches the
   manual play/stop/play cadence that empirically fires cold tubes (repeated
   short drives heat the filament without holding continuous drive into an
   unstruck load).
4. **Run.** On strike, step to **75% run duty** (= VK3HZ P100 for the 240V
   board) and hold continuous. Run duty is then set by desired power.

**Filament physics:** the magnetron needs ~2 s to reach emission temperature
(Panasonic NN-GF668M: "approximately 2 seconds are required for heating of
magnetron filament"). The 2500 ms attempt window covers that; the retry loop
handles tubes that need more than one window.

**Timer handling (crash fix):** the hardware timer is started ONCE and never
re-armed. Duty changes update only `sinkTicks` live. Re-arming a running timer
(calling timerStartUs on the run transition) caused a Guru Meditation /
InstrFetchProhibited crash at PC=0x00000001 — do not reintroduce that.

**Why status-gating is the safety mechanism:** the inverter runs a constant-power
loop. Driven continuously into a load NOT drawing current (unstruck,
off-resonance, or no load), the loop concludes "need more power" and pushes its
internal switching duty up until the IGBTs fail. Not theoretical — a Frankenboard
Q701 failed within seconds at **30% duty in force mode** (open-loop, status
ignored), fuses intact, fault faster than fuse response
(`docs/failure_analysis/`). Watching pin 1 for strike before going continuous is
exactly what prevents that.

## Polarity / pin reference (confirmed)
- **CN701 pin 3** = command IN (we drive). 222 Hz, duty = power, active-high.
- **CN701 pin 1** = status/feedback OUT (we READ, never drive). Open-collector
  from the inverter, **pulled HIGH by the DPC's pull-up**; the inverter pulls it
  **LOW at 110 Hz when the magnetron draws current**. **LOW = struck.** With the
  DPC removed the line sits at 0V — so in our standalone rig we supply the pull-up
  and read the line. Driving this line previously corrupted a board: read-only.
- **CN701 pin 2** = 0V common.

## Duty values — reconciled
- **Startup pulse: 33%** @ 222 Hz (the "~38%" mentioned at the bench was a
  near-miss for 33%).
- **Run: 75%** @ 222 Hz on strike (VK3HZ P100 for 240V; cap 75%, >75% over-drives).
- **~85% is the 120V capture only** — NOT used on the 240V board (not portable).

## Document history
- 2026-06-07 Created from FBLOW-RETRY-v5 (session "New Panasonic boards arrival",
  2026-06-06). Documents the cross-install provenance, the 33%-pulse /
  watch-pin1-LOW / 8x-retry / 75%-run status-gated sequence, the 3-read glitch
  guard, the single-arm timer crash fix, and the pin-1-LOW = struck polarity.
  CORRECTS an earlier draft that wrongly claimed the cross-install capture
  refuted the 75% run-duty cap: the cross-install establishes the protocol, not
  the 240V run duty. 75% run is the proven value; 85% is the 120V capture and
  does not port. Also supersedes the "warm-up burst then drop" framing.

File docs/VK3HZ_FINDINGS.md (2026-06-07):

# VK3HZ Reverse-Engineering Findings — Panasonic Microwave Inverter HV PSU

Captured 2026-05-30 from David Smith VK3HZ's original PDF
(http://www.vk3hz.net/amps/Microwave_Oven_Inverter_HV_Power_Supply.pdf).

Hosted locally in repo because the canonical URL is intermittently unavailable.

See also `docs/reference/sources_and_official_docs.md` for the official Panasonic
Technical Training Manual, the avdweb contactless HV test, and why no official
drive-signal spec exists.

Source PSU: Panasonic NN-S550WF (circa-2000). NOTE: earlier revisions of this
file called it "single-IGBT" — that is WRONG. The board is a TWO-IGBT
half-bridge: Q701 (GT60N90, main switch) + Q702 (GT30J322, second/flywheel
device) — the same half-bridge resonant topology as the F6645-series. The
findings therefore apply across the Panasonic inverter family — F606Y-series
and F6645-series (dual-IGBT, 240V) share the same half-bridge architecture and
the same DPC↔inverter command interface — per the author's note, the avdweb
re-engineering (which explicitly calls it "a half-bridge converter of 1000W"),
and the tomtechtod9200 YouTube RE of the F66459X91AP (dual-IGBT). The "dual vs
single IGBT" distinction is NOT a reason to treat VK3HZ's data as inapplicable.

---

## Architecture summary

- High Voltage PSU: 165×105×60 mm, 650 g
- Mains rectifier + IGBT switching at ~30 kHz internal frequency
- HV transformer drives half-wave doubler rectifier → ~4 kV DC at 300 mA
- HV filter caps only 8200 pF each (effectively 4100 pF in the doubler)
- Mains filter cap is small (~4 µF) — DELIBERATE design choice; 100 Hz ripple
  on the HV makes the magnetron stop oscillating during low-voltage portions
  of the line cycle, which helps spectrum sharing with WiFi etc.
- Output is **constant-POWER regulated**, not constant-voltage. The board
  senses input current internally and adjusts switching duty to deliver
  the commanded power. At a given P-level, output power stays within ~1 W
  across a 50% variation in load current.

## CN701 interface (3-pin DPC connector)

Two opto-isolated lines + ground:

| Pin | Role | Notes |
|-----|---|---|
| Command | DPC → Inverter | TTL-level 220 Hz square wave; duty cycle = power setpoint |
| Status  | Inverter → DPC | 110 Hz square wave, 50% duty, **only present when magnetron is drawing current** |
| GND | Opto-isolated common | Logic ground reference |

(Pin numbering varies between board generations; see project notes for the
F6645M301GP specifically. The roles are the constant.)

The control and status signals are synchronized to each other but unrelated
to AC mains frequency or phase.

Signal levels: TTL (2-3 V observed on a meter for "on" state because of
duty averaging — actual peaks are 5 V).

## Canonical command duty cycle table (KEY)

This is the table the DPC sends per power level. **First number is steady-state,
second number applies during the warm-up phase before status appears.**

| Power | On time (ms)  | Duty (%) | Cycling |
|---|---|---|---|
| P10 | 1.5 / 1.1 | 33 / 25 | 4 s on / 18 s off |
| P20 | 1.5 / 1.1 | 33 / 25 | 11 s on / 11 s off |
| P30 | 1.5 / 1.1 | 33 / 25 | 18 s on / 4 s off |
| P40 | 1.5 / 1.1 | 33 / 25 | Continuous |
| P50 | 1.5 | 33 | Continuous |
| P60 | 1.8 | 40 | Continuous |
| P70 | 2.5 | 55 | Continuous |
| P80 | 2.8 | 62 | Continuous |
| P90 | 3.1 | 69 | Continuous |
| **P100** | **3.4** | **75** | Continuous |

**P100 = 75% duty. Anything above 75% is over-driving the inverter.**

Period = 1/220 Hz ≈ 4.55 ms. So "1.5 ms on" out of 4.55 ms ≈ 33% duty.

## Startup sequence (CRITICAL — this is what we were missing)

> **SUPERSEDED for our standalone driver — see `docs/STARTUP_PROCEDURE.md`.**
> The "warm-up phase = higher duty then drop" below is the OEM DPC's *low-power
> cycling* behaviour, NOT our method. Our verified, bench-proven startup is:
> pulse the command 1-3 s on CN701 pin 3, watch pin 1 for LOW (= strike),
> repeat until struck, then run continuous at the desired-power duty. Status-
> gated, which is what prevents the 30%-force-mode IGBT failure.

For low-power settings (P10-P40), the DPC's behavior on START:

1. **Warm-up phase**: send a HIGHER duty than the requested power level
   (specifically, 25-33% duty / 1.1-1.5 ms on) to bring the magnetron
   filament up to operating temperature.

2. **Wait for status signal**: monitor the inverter's 110 Hz status output.
   The inverter only emits this signal when it detects current flowing —
   i.e., when the magnetron is warm and oscillating.

3. **Drop to requested power**: once status is seen, the DPC drops the
   command duty cycle to the requested P-level.

For higher power levels (P50+), the duty is continuous at the same value
throughout — but the DPC still waits for status confirmation before
declaring "running."

## Why the constant-power architecture is dangerous to drive open-loop

The inverter's internal control loop tries to deliver the commanded power
to the load. If there's no magnetron, no load, or the resonant tank is
off-resonance:

- The inverter sees insufficient current draw
- Its loop concludes "I need more power"
- It increases internal switching duty to compensate
- Without bounded protection, this can drive the IGBTs into shoot-through
  or off-resonance overcurrent
- The smaller IGBT typically fails first (lower current rating)

This is why **status-gated operation matters**: the DPC's job is to ensure
the inverter is actually running into a proper load before committing to a
power level. Bypass that gate and the inverter happily destroys itself.

## Quoted measured output (NN-S550WF specifically)

Output voltage/current measurements from VK3HZ's bench testing:

| Power | On (ms) | Min Load V/I/P | Max Load V/I/P |
|---|---|---|---|
| 40% | 1.1 | 3730 V / 147 mA / 548 W | 2560 V / 210 mA / 538 W |
| 50% | 1.5 | 3890 V / 175 mA / 681 W | 2720 V / 250 mA / 680 W |
| 60% | 1.8 | 3980 V / 192 mA / 764 W | 2820 V / 275 mA / 776 W |
| 70% | 2.5 | 4200 V / 240 mA / 1008 W | 3020 V / 330 mA / 997 W |
| 80% | 2.8 | 3650 V / 300 mA / 1095 W | 3020 V / 365 mA / 1102 W |
| 90% | 3.1 | 3930 V / 300 mA / 1179 W | 3080 V / 385 mA / 1186 W |
| 100%  | 3.4 | 4120 V / 300 mA / 1236 W | — (current limited) |

Note constant-power behavior: at P50, current can vary ~50% but output
power varies only 1 W.

Minimum continuous output is ~550 W (P40). For lower average power, the
DPC cycles P40 on/off over a 22-second window. The inverter itself
cannot run below P40 continuously.

## Original Panasonic IGBT modification (Service bulletin)

The original NN-S550WF had:
- Q701 (main switch): GT60N90 — 900 V / 60 A
- Q702 (smaller switch): GT30J322

Panasonic issued a service modification kit replacing:
- GT60N90 → **GT60N321** (1000 V vs 900 V — higher voltage headroom)
- GT30J322 → unchanged but supplied (likely indicating post-blowup replacement)
- **330 pF cap on control board → 56 pF**

Translation: Panasonic acknowledged the original IGBT was undersized AND
that gate timing needed adjustment. The control-cap change (~6× smaller
capacitance) means faster gate switching.

For your F6645M-series (240V dual-IGBT), bench inspection of the factory boards
shows the originals are **GT50N322 (1000V/50A, big/low-side) + GT35J321
(600V/35A, smaller/high-side)** — NOT the "GT50J327" earlier listed here. That
correction matters: the 600V GT50J327 was a Frankenboard *repair* part, and a
600V device in the resonant-switch (low-side) position — where the switch node
swings well above the ~340V bus — is a leading suspect for the repeated Q701
deaths. The factory boards ship with the correct 1000V part. Modern Infineon
TRENCHSTOP RC-H5 (IHW40N120R5 + IHW30N120R5, 1200V) are a further upgrade if a
replacement is ever needed.

## Implications for our standalone firmware (TL;DR)

1. **Send 50% duty during warmup, not the requested run duty.**
2. **WAIT for the 110 Hz status signal from the inverter before going to RUN.**
   Without status confirmation, the magnetron isn't oscillating; driving
   the inverter blindly is what destroys IGBTs.
3. **Hard-cap maximum duty at 75%** — anything above is above-spec.
4. **Don't drive a fake "feedback" signal onto the status line.** The
   inverter generates that signal; we read it, we don't write it.
5. **A magnetron load must be physically connected.** No-load operation
   confuses the constant-power regulator.

These are exactly the changes in firmware commit `3128125`.

## Sources

**Primary references (archived in-repo, used as authoritative):**

- **`docs/reference/Panasonic_ServiceCD_Schematic.png`** — Panasonic's own
  schematic of the HV inverter PSU from the Panasonic Service CD. Most
  authoritative non-proprietary reference for the topology and component
  values. Reproduced in the VK3HZ PDF below.
- **`docs/reference/Microwave_Oven_Inverter_HV_Power_Supply.pdf`** —
  David Smith VK3HZ's writeup including the Panasonic schematic plus
  bench measurements of operational behavior (the 220 Hz / 110 Hz /
  30 kHz signal characterization, power tables, constant-power analysis).

**Supplementary references (lower priority):**

- `docs/reference/Panasonic_Inverter_Schematic_Annotated.pdf` — Russian
  community reverse-engineering. Contains some errors; use only when
  Panasonic schematic doesn't have enough detail.

**Original online sources** (for citation; project doesn't depend on
these staying online):

- VK3HZ PDF: http://www.vk3hz.net/amps/Microwave_Oven_Inverter_HV_Power_Supply.pdf
- Docplayer mirror: https://docplayer.net/21544207-Panasonic-microwave-oven-inverter-hv-power-supply.html
- electronicshelponline blog: https://electronicshelponline.blogspot.com/2018/11/panasonic-microwave-oven-nn-s550wf.html
- tomtechtod9200 YouTube (F66459X91AP RE): https://www.youtube.com/watch?v=LZb6v0JMOuU
- Panasonic Tech Guide for Inverter Microwaves: https://media.datatail.com/docs/manual/371449_en.pdf

**Related Panasonic service manuals** (no schematic, but useful for
test procedures and parts cross-reference):

- NN-SD798S (Latin America 120V single-IGBT F606Y8M00AP):
  https://www.csportal.panasonic-la.com/DESCARGASPLA/PLA/ELECTRODO/MICROONDAS/INVERTER/NN-SD798SRPH/MANUAL%20DE%20SERVICIO/sd798s_rph.pdf
- NN-GD376S (230V dual-IGBT F606YM300BP):
  https://www.manualslib.com/manual/801129/Panasonic-Nn-Gd376s.html
- NN-ST657S (closest match for F6645M301GP family):
  https://www.manualslib.com/manual/1871563/Panasonic-Nn-St657s.html

**Attribution:** The VK3HZ document is copyright David Smith VK3HZ
(vk3hz [at] wia.org.au). The community schematic source is unknown
(Russian-annotated). Both are archived here for project continuity
under fair-use reference purposes; cite the originals in any
publication or derivative work.

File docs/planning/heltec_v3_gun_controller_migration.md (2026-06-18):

# Plan: Heltec WiFi LoRa 32 V3 as the consolidated gun controller

**Status:** PLANNED (evaluating). Not yet built.
**Date:** 2026-06-16
**Board:** Heltec WiFi LoRa 32 V3 (ESP32-S3FN8 + Semtech SX1262 + 0.96" SSD1306 OLED)
**Owns:** Aideepen/Heltec V3 2-pack already on hand (the LoRa-link boards).

## Why

Today the gun side is an ESP32-S3 Supermini running the inverter controller,
with a *separate* Lora32 planned for the 915 MHz out-of-band link. The Heltec
V3 already integrates the SX1262 LoRa radio **and** a status OLED on one
ESP32-S3 board. Migrating the gun controller onto a Heltec collapses three
things into one:

- inverter + RTD + fan controller (current firmware)
- 915 MHz LoRa node (deadman link / radio-dark-on-2.4 GHz plan)
- gun-side status display (temps, RF state, link health, faults)

The 2.45 GHz desense problem stays solved: LoRa is 915 MHz, well clear of the
magnetron, and WiFi/BLE (2.4 GHz) stay OFF per the radio-dark plan.

## Hard constraint: Heltec reserves many GPIOs

These are used by onboard peripherals and are **off-limits** for our signals:

| Function | Pins |
|---|---|
| SX1262 LoRa | 8 (NSS), 9 (SCK), 10 (MOSI), 11 (MISO), 12 (RST), 13 (BUSY), 14 (DIO1) |
| OLED I2C (SSD1306) | 17 (SDA), 18 (SCL), 21 (RST) |
| Vext (powers OLED/ext, active LOW) | 36 |
| Battery / misc | 1 (VBAT ADC), 37 (ADC ctrl), 35 (LED), 0 (PRG button) |
| USB / strapping (avoid) | 19, 20, 45, 46 |
| SPI flash (internal) | 26-32 |

**Six of the current Supermini pins collide** and must move:
RTD SCK 11 / MOSI 12 / MISO 13 (= LoRa SPI bus), CS_mag 1 (= VBAT), fan_mag_tach
10 (= LoRa MOSI), fan_hs_pwm 8 (= LoRa NSS).

## Proposed remap (12 signals onto free pins)

Free, safe pins on the V3: 2, 3, 4, 5, 6, 7, 33, 34, 38, 39, 40, 41, 42, 47, 48.

| Signal | Supermini (now) | Heltec V3 (proposed) | note |
|---|---|---|---|
| inverter cmd | 4  | 4  | keep |
| inverter status | 5  | 5  | keep (1k + ~1k pulldown divider) |
| zero-cross | 7  | 7  | keep |
| fan_mag PWM | 2  | 2  | keep |
| fan_hs tach | 3  | 3  | keep |
| RTD CS_hs | 6  | 6  | keep |
| RTD SCK | 11 | 33 | move (was LoRa MISO) |
| RTD MOSI/SDI | 12 | 34 | move (was LoRa RST) |
| RTD MISO/SDO | 13 | 47 | move (was LoRa BUSY) |
| RTD CS_mag | 1  | 48 | move (was VBAT) |
| fan_mag tach | 10 | 38 | move (was LoRa MOSI) |
| fan_hs PWM | 8  | 39 | move (was LoRa NSS) |

Spare: 40, 41, 42. ESP32-S3 has no input-only pins and all GPIO are
interrupt-capable, so tach inputs / LEDC PWM / bit-bang SPI all work on any of
the above. The manual-CS RTD driver already takes explicit pins, so only the
`PIN_RTD_*` / `PIN_FAN_*` constants change — no logic changes.

**VERIFY before wiring:** confirm these internal-pin assignments against the
exact board's pinout (Heltec revs occasionally shuffle). RF discipline near the
magnetron still applies (RC filters on sense lines are load-bearing).

## OLED status page (new)

0.96" 128x64 mono SSD1306 on I2C (SDA 17 / SCL 18 / RST 21), powered via Vext
(drive GPIO36 LOW to enable). Library: U8g2 or Heltec_ESP32. Proposed readout:
mag °C / hs °C, RF ON/OFF + duty, LoRa link OK/LOST (deadman heartbeat age),
fault flags. Keep refresh modest; OLED is on the I2C bus only, no pin conflict
with the remap above.

## Migration steps (when committed)

1. Remap `PIN_*` constants in `panasonic_dual_igbt_esp32s3` per the table.
2. Add SX1262 LoRa deadman link (gun fires only while receiving heartbeat;
   cut output within ~200-300 ms of link loss; fail-safe to OFF).
3. Add OLED status page.
4. Bench-verify inverter + dual RTD + fans on the Heltec before going to the gun.

---

# Open verification items (RTD/fan subsystem) — carry-over

These are NOT done yet on the current Supermini build and carry into the Heltec
plan unchanged:

- [ ] **2nd RTD (heatsink) board** — wire a known-good MAX31865 to CS_hs
      (Supermini GPIO6). Magnetron channel already reads ~24 C (raw ~8349,
      flt 0x00). Expect heatsink to read ambient once connected; currently shows
      -242 C = "no sensor present", which is the correct unconnected reading.
- [ ] **Fan speed control** — verify the 25 kHz LEDC PWM actually varies both
      4-wire fan speeds across the thermal curve (not just full-on).
- [ ] **Fan tach reporting** — confirm both tach inputs return real RPM in the
      web UI / `status` (currently "0 rpm @ 40%" with fans possibly not spun up
      or tach not wired).
- [ ] **Commit/push firmware v19** — adds live temps (C and F, both sensors) to
      the serial `status` command. Flashed/tested but may not be pushed yet.

## Known-good hardware inventory (post 2026-06-16 bench)

- MAX31865 boards: 1 new (reads 24.4 C on gun, confirmed) + old #2 (passed comms
  test). Old #1 = dead (discarded). 1 bricked ESP32-S3 (discarded).
- Root cause of the long RTD saga: MAX31865 CS->clock polarity-lock gap missing
  in the ESP32 SPI driver; fixed by manual-CS in firmware v18. See
  `docs/failure_analysis/2026-06-15_max31865_rtd_bringup_blocked.md`.

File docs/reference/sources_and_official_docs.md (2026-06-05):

# Sources & Official Documentation — Panasonic Inverter HV PSU

Catalogue of what exists (official) vs what had to be reverse-engineered, for
driving these boards standalone. Short version: **the drive signal is RE-only.**

## Official Panasonic documentation

### "Microwave Ovens with Inverters — Technical Manual"
- Panasonic Services Company, National Training Department (Secaucus, NJ),
  prepared by Cesar Perdomo. A technician *training* manual for the whole
  inverter oven line — the closest thing to an official bench guide for these
  boards.
- Copies: ManualsLib (manual id 764833) and PDF at
  `https://media.datatail.com/docs/manual/371449_en.pdf`
  (also mirrored on avdweb, see below).
- What it covers:
  - Architecture: DB701 bridge -> DC bus -> IGBT half-bridge switched by
    20-40 kHz PWM from the DPC microprocessor; HV transformer is part of the
    oscillator resonance circuit, so drive frequency shifts with load/power.
  - HV transformer: ~2000 V secondary + ~3 V AC FILAMENT winding; D701/D702
    half-wave doubler -> ~4000 V DC. CT701 current transformer feeds output
    back to the DPC (constant-power loop).
  - Official test method: it states "it's neither necessary nor advisable to
    attempt measurement of the high voltage." Instead use an **AC ammeter**:
    1 L water beaker in the cavity, unplug the 2-pin HV connector at CN703,
    set the oven to HIGH, and read mains current to distinguish a magnetron
    fault from an inverter fault.
  - H97/H98/H99 self-diagnostic codes = "no microwave oscillation" fault
    areas (magnetron / inverter circuit). First check: magnetron filament for
    open or short-to-casing.

### Why there is NO official drive-signal spec
Panasonic treats the inverter PSU as a **non-repairable replaceable module**.
Technicians swap the whole unit; they never bench-drive it standalone. So the
220 Hz DPC->inverter command duty table was never published by Panasonic and
does not exist in any official document. Searching for it is a dead end. The
authoritative source for the command signal is the reverse-engineering work
below.

## Reverse-engineering sources (the actual drive-signal authority)

### VK3HZ (David Smith) — `docs/VK3HZ_FINDINGS.md`
- Source board: Panasonic NN-S550WF. TWO-IGBT half-bridge (Q701 GT60N90 main +
  Q702 GT30J322 flywheel) — NOT single-IGBT.
- Gives the 220 Hz command duty table per power level, the 110 Hz status
  signal behaviour, the warmup-then-drop startup, and measured HV output.
- Mains voltage of his unit is NOT stated in the doc; the 230 V assumption is
  inferred (AU callsign + ~1236 W P100). Treat his duty NUMBERS as indicative,
  the BEHAVIOUR as authoritative.

### avdweb (Albert van Dalen) — contactless HV test (KEY bench tool)
- `https://avdweb.nl/tech-tips/electronics/panasonic-hv-psu`
- Calls the board "a half-bridge converter of 1000W, 470 g" — confirms
  half-bridge / two-switch topology, and that standalone and in-oven signals
  are identical.
- SAFE go/no-go test without probing the 4 kV node: wire loop around the
  transformer core + 1N4007 diode + 10 ohm / 1 W resistor in series. If the
  inverter is producing HV:
    - **~1.6 V with the magnetron connected**
    - **~1.9 V with the magnetron disconnected**
  Near-zero while it hums = switching but NOT delivering (tank/oscillation
  fault). Real reading = HV is being made; problem is downstream (filament
  heat / strike / tube).
- Hosts a mirror of the Panasonic Technical Guide:
  `https://avdweb.nl/images/Tech-tips/Panasonic-HV-inverter/Technical-Guide-Microwave-Ovens-with-Inverters.pdf`

### tomtechtod9200 (YouTube) — F66459X91AP RE
- Reverse-engineering of an F66459X91AP (dual-IGBT sister board). Confirms the
  ~220 Hz command signal and the shared command-interface architecture.

## Filament heating (relevant to no-strike debugging)
The ~3 V filament winding is ON the HV transformer, driven by the same
oscillation — so filament heat scales with how hard the tank is driven and only
exists while the inverter is oscillating. This is the documented basis for the
warmup-then-drop startup: drive hard enough to heat the filament + sustain
oscillation, the tube strikes, back-bombardment then keeps the cathode hot, and
the drive can be reduced. (Panasonic Technical Guide + VK3HZ + avdweb all
consistent on this.)

## Chinese 家电维修 (appliance-repair) bench procedures

The factory ICT/rework spec is ODM-internal and didn't surface publicly, but the
Chinese repair-technician literature documents bench procedures for exactly this
board family and the "hums, won't strike" symptom. These are the de-facto bench
equivalent.

### Worked diagnostic case — Panasonic inverter, no oscillation
Source: `https://m.iask.sina.com.cn/b/1H1tCU8UqHJf.html`
Baseline it states: a working magnetron needs (1) filament energised, current
>10 A, and (2) >1000 V between filament and tube casing. Diagnostic order:

1. **Magnetron** — disconnect FA/F. Filament resistance very small (~0.3 ohm
   measured); each filament pin to casing must be infinite (OL).
2. **HV established, WITHOUT a 4 kV probe** — a normal meter only reads to
   ~500 V, so don't measure live. Instead: power the oven, heat ~3 s, stop,
   wait ~10 s, then measure the doubler/bus capacitor (point A) to ground. A
   healthy HV section shows a residual voltage that starts at several hundred
   volts and decays to zero (case measured ~400 V decaying). If it reads
   nothing, that section isn't delivering. (Second non-lethal HV test alongside
   the avdweb contactless loop.)
3. **Filament winding** — supplies the magnetron ~3 V; winding resistance <1 ohm.
4. **Connections** — the case's actual culprit: every individual component
   tested good, but the assembly was dead. Fault was bad contact in the
   connecting wires/connectors. Parts-good-but-dead-assembled => suspect wiring,
   not components. (Relevant to a custom launcher mount.)

### Other bench/technician sources
- "变频/定频微波炉金牌维修实训" — vocational training text, full chapters on
  magnetron substitution, filament-socket faults, HV testing, microwave-output
  measurement for INVERTER ovens (`opac.peihua.cn`, book id 01h0165797).
- "松下NN-GS575W变频微波炉常见故障速查表" — model-specific fault quick-reference
  (`gzweix.com`).
- 松下微波炉变频板维修 writeups (`shskwx.com/news/43168.html`, `/75177.html`).

## Drive signal vs feedback signal (CN701) — consolidated

**Drive / command (DPC -> inverter):**
- ~220-222 Hz square wave (measured 221.8 Hz / 4509 us). COMMON to 120 V and
  240 V boards. This is NOT the switching frequency — the inverter's own MICOM
  generates the 20-40 kHz IGBT switching internally; the 220 Hz command is only
  the power SETPOINT.
- Duty cycle = power level. Active-high (more HIGH = more power, INVERT_CMD=false).
- TTL, ~5 V peaks (meter reads 2-3 V due to duty averaging). Opto-isolated
  (IC702 + D706 + R733). ESP32 drives 3.3 V — works, but ~45% of design opto LED
  current; 74AHCT1G125 buffer gives a true 5 V if striking proves flaky.
- Duty magnitude is voltage-dependent: VK3HZ 230 V table P100 = 75% (>75%
  over-drives); the 120 V personal-oven capture was ~85%. Not portable across
  mains voltage.

**Feedback / status (inverter -> DPC):**
- 110 Hz square wave, fixed 50% duty — exactly half the command frequency,
  synchronised to it, unrelated to AC mains.
- PRESENT ONLY when current is being drawn — i.e., the magnetron is warm and
  oscillating. Absence = not struck. This is the inverter reporting "I'm running
  into a real load."
- Opto-isolated, READ-ONLY. Never drive it (driving 110 Hz onto this line
  corrupted a board previously). We tie it to GND through 1k when running
  open-loop, but reading it gives a direct electrical "did it strike" readout.
- Separate from the INTERNAL feedback: CT701 (current transformer) -> MICOM
  closes the constant-power loop inside the inverter. The 110 Hz status is the
  external summary of that to the DPC.

## Standalone-driver community (Fusor / ham RF) — open-loop drive method

These builders have driven Panasonic inverter boards open-loop for ~20 years.
Independent confirmation of the drive method (NOT Panasonic docs; treat the
per-cycle duty table as still RE-only, but the hookup/sequencing is well
established). Pin NUMBERING in these old posts is swapped vs some of our other
refs (they call command = pin 3, status = pin 1) — the ROLES/colors are the
constant, not the pin numbers.

### 4-wire standalone hookup (Fusor t=4562, t=4820)
- 2x AC mains lines.
- Control plug: pin 2 = common/ground (tie to your control-circuit ground).
- COMMAND pin: accepts an oscillatory TTL signal, duty = power, via opto.
  KEY: "the board produces FULL power if +5 VDC is applied to this pin." And
  separately: "by putting 2-3 V on the command pin the optocoupler turns on and
  power turns on — it's just on/off." So a static 5 V runs it at full; the
  duty cycle only modulates power BELOW full.
- STATUS pin: optional. To read the inverter's feedback "on" signal, pull it up
  to your +V through ~22k (22k to +12V quoted). It's the 110 Hz square wave,
  present only when the magnetron draws current.
- Control side is fully opto-isolated — can float relative to the board.

### Startup sequencing (Fusor t=4562)
"The AC mains must be hooked up for some small fraction of a second BEFORE 5 V
is applied or it won't be recognized." => power the board first, THEN assert
the command. We have not been controlling this order explicitly.

### Warmup behavior — independent confirmation (Fusor t=4820)
"The front panel sends a PWM signal to the inverter. At startup the PWM is set
at a HIGH level until the magnetron starts drawing current, i.e. the filament
has warmed up, then the inverter outputs a squarewave [110 Hz status] to tell
the front panel." => start high, hold until filament warms + tube draws current,
status appears only then. Matches VK3HZ, avdweb, and the patents.

### Drive LEVEL — the builders used a real 5 V
"Full power if +5 VDC"; "2-3 V turns the optocoupler on." 5 V = full opto drive.
Our ESP32-S3 GPIO drives 3.3 V — between "turns on" and "full 5 V." This is the
marginal-opto-current concern; the community standard is 5 V.

### Magnetron mode-hopping at partial power (Fusor t=5022)
"Find the lowest-power magnetron you can — the Panasonic one is a monster. They
mode-hop at low/medium powers, in and out of the resonance of the high-Q cavity;
a small one does this less." => "builds toward strike then drops out" at partial
drive can be mode-hopping, not a board fault.

## Patents (out-of-patent prior art confirming behavior)
- US4825028 "Magnetron with microprocessor power control": duty cycle of the
  power-control signal sets magnetron power via variable ON/OFF intervals; and
  "the microprocessor is operable to DELAY operation of the magnetron until the
  filament current has warmed up the filament." (warmup-before-strike as a claim)
- US4620078 "Power control circuit for magnetron": holds filament temperature
  above a predetermined minimum "set sufficiently high to avoid moding" while
  anode voltage is below the strike threshold in standby. (filament must be hot
  enough to strike cleanly / avoid moding)
- US4296296: duty-cycle magnetron supply; controlling signal is a square wave.
- US6936803B2 (already in repo refs): inverter current-feedback control loop.

## Panasonic service manual with published power table (right voltage class)
NN-GF668M service manual (Panasonic Shanghai), 230V 50Hz inverter oven, prints
the variable-power table (user-level average-power cycling, NOT per-cycle duty):
  HIGH 100% (22s on/0 off), MEDIUM 60%, LOW 45%, DEFROST 30% (16/6),
  SIMMER 25% (15/7), WARM 10% (8/14).
Confirms IGBTs switched by 20-40 kHz PWM from the DPC microcomputer. Public PDF
at partmaster.co.uk (nngf668mspg service manual).

## KEY OFFICIAL FINDING — magnetron filament warmup (~2 seconds)

From the NN-GF668M service manual (Panasonic, 230V), variable-power section,
verbatim: "The ON/OFF time ratio does not correspond with the percentage of
microwave power since approximately 2 seconds are required for heating of
magnetron filament."

This is Panasonic stating the warmup requirement with a NUMBER: ~2 s of filament
heating before microwave power. It ties together every other source:
- Patents US4825028 / US4620078: delay magnetron operation until filament warms;
  hold filament hot enough to strike / avoid moding.
- Fusor builders: "start the PWM high until the magnetron draws current, i.e. the
  filament has warmed up, then the status squarewave appears."
- avdweb / Panasonic Tech Guide: ~3 V filament winding on the HV transformer.

PRACTICAL CONSEQUENCE for standalone bench bring-up: brief on/off taps never
deliver the continuous ~2 s. A magnetron needs a SUSTAINED run (hold several
seconds) for the cathode to reach emission and strike. "Hums, no strike" on
short bursts is consistent with the filament never reaching temperature. The
strike develops a couple of seconds INTO a held run, not on a tap.

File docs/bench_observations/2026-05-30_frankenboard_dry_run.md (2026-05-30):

# Frankenboard dry-run observation — 2026-05-30

Mains applied to Frankenboard with **IGBTs not installed** (sitting on heatsink,
not soldered to PCB), ESP32 sending command via `force` + `on` (open-loop,
no status check). Scoped Q701 gate-to-emitter and CN701 pin 1 (status output).

## Setup

- Inverter board: F6645M301GP Frankenboard (Q701/Q702 IGBTs unsoldered)
- Q701 = original Toshiba GT50J327 (reinstalled after IGBT failure of replacement)
- Q702 = Infineon IHW30N120R5 (survived the original failure event)
- Both IGBTs mechanically on heatsink, electrically isolated from board
- ESP32 firmware: VK3HZ-correct rewrite (commit `3128125`)
- Mode: `force` + `on` (open-loop drive, ignoring status feedback)
- Drive: 222 Hz, ~40% duty on CN701 command input
- Mains: 240 V AC applied through 2 A fast-blow fuse
- Both scopes battery-powered (DS213 + UT81B) — fully isolated

## Observations

### CN701 pin 1 (status output) — UT81B + ESP32 statusinfo

**No signal observed.** ESP32 reports 0 edges on GPIO5. This is **expected
and correct behavior**:

- Inverter's status output is asserted only when CT701 senses primary current
- With IGBTs not installed, no primary current can flow regardless of gate drive
- ASIC correctly refrains from asserting status — no false signal
- Confirms the status-detection path on the ASIC is working as designed

### Q701 gate pad — DS213, gate-to-emitter probe

**Active gate drive present.** Voltage and frequency measured across a
7-second capture:

| Sample | Vp-p (V) | Frequency (kHz) | Notes |
|---|---|---|---|
| ~0.5s  | 26.8 | 29.3 | Mid-range, safe ZVS region |
| ~2.0s  | 28.0 | 32.8 | Higher freq, safe ZVS region |
| ~3.5s  | 27.2 | 32.6 | Mid-high freq, safe ZVS region |
| ~5.0s  | 26.8 | **21.2** | **BELOW f_r — capacitive mode** |
| ~6.5s  | 27.2 | **22.4** | **BELOW f_r — capacitive mode** |

Voltage: stable ~27 Vp-p across all samples (bias rail solid at ~+20 V).

Frequency: **HUNTING between 21.2 kHz and 32.8 kHz**.

## Interpretation

### Why the controller hunts

The Panasonic ASIC closes a current-control loop using CT701 (input current
transformer) feedback. With no IGBTs and therefore no primary current, the
loop never converges:

- ASIC commands switching → no current measured → adjusts frequency to
  "increase power" → sweeps toward LC resonance to maximize transfer →
  still no current → keeps adjusting → never settles

The sweep range observed (21-33 kHz) represents the controller's full
operating range probing for a working operating point.

### Why this matches the failed bring-up

Per the SPICE simulation in `spice/results/` with the Frankenboard's
measured C701 = 0.18 µF and estimated L_tank ≈ 250 µH:

- Calculated LC resonance f_r = 1 / (2π√(LC)) = **23.7 kHz**
- Above f_r: ZVS achieved, IGBTs survive
- Below f_r: hard switching (capacitive mode), IGBTs die in milliseconds

**The 21.2 kHz and 22.4 kHz observations are BELOW the predicted f_r.**

This is the exact failure mechanism the SPICE simulation predicted:
when the controller is hunting and lands below f_r, an installed IGBT
(Q701 specifically — the low-side switch) would see hard switching at
full bus voltage. Result: catastrophic dissipation in the device, leading
to the symmetric C-E-G short pattern observed in the original failure.

### What this DOESN'T tell us

We don't know if the same hunting behavior would occur on a healthy
factory board with the design-intent component values. Two possibilities:

1. **Normal behavior:** All Panasonic boards hunt like this at startup
   without load, but the controller's internal protection (current limit,
   minimum f_sw clamp, or dV/dt sensing) protects the IGBTs during the
   brief moments below f_r. Healthy boards settle quickly once a magnetron
   provides load feedback.

2. **Frankenboard-specific:** Our Frankenboard has component values
   (especially C701 = 0.18 µF on this revision vs 0.1 µF on the older
   Panasonic schematic) that put the LC resonance in a place the
   controller's hunting range bottoms out below f_r. Other boards would
   not show this pattern.

We cannot distinguish between these without a known-good factory board
to compare against.

## Conclusion

The Frankenboard remains a **DO NOT POWER WITH IGBTS INSTALLED** candidate
until either:

a) A factory board comparison shows this hunting is normal, in which case
   we know the IGBTs survive briefly-below-f_r operation by design.

b) The hunting on a factory board converges to a stable above-f_r operating
   point quickly enough that the brief sub-f_r excursion isn't destructive.

Either way: **first fire test on a fresh factory board, not the Frankenboard.**

## Status signal correlation

The absence of status signal on CN701 pin 1 is **separately informative**.
It confirms:

- The previous firmware's bug (driving 110 Hz onto pin 3) was creating a
  signal where the ASIC's own status logic intended none to exist
- Without that corruption, the status line is correctly silent at idle
- The new firmware's status-gated startup will correctly ABORT when no
  status appears — which is the safe behavior

## Captured scope frames

See companion JPGs in this folder:
- `2026-05-30_frankenboard_dry_run_29kHz.jpg` — 29.3 kHz, ZVS region
- `2026-05-30_frankenboard_dry_run_33kHz.jpg` — 32.8 kHz, ZVS region  
- `2026-05-30_frankenboard_dry_run_21kHz_DANGER.jpg` — 21.2 kHz, BELOW f_r
- `2026-05-30_frankenboard_dry_run_22kHz_DANGER.jpg` — 22.4 kHz, BELOW f_r

All frames show DC-coupled, 10 V/div, 5 µs/div on the DS213.

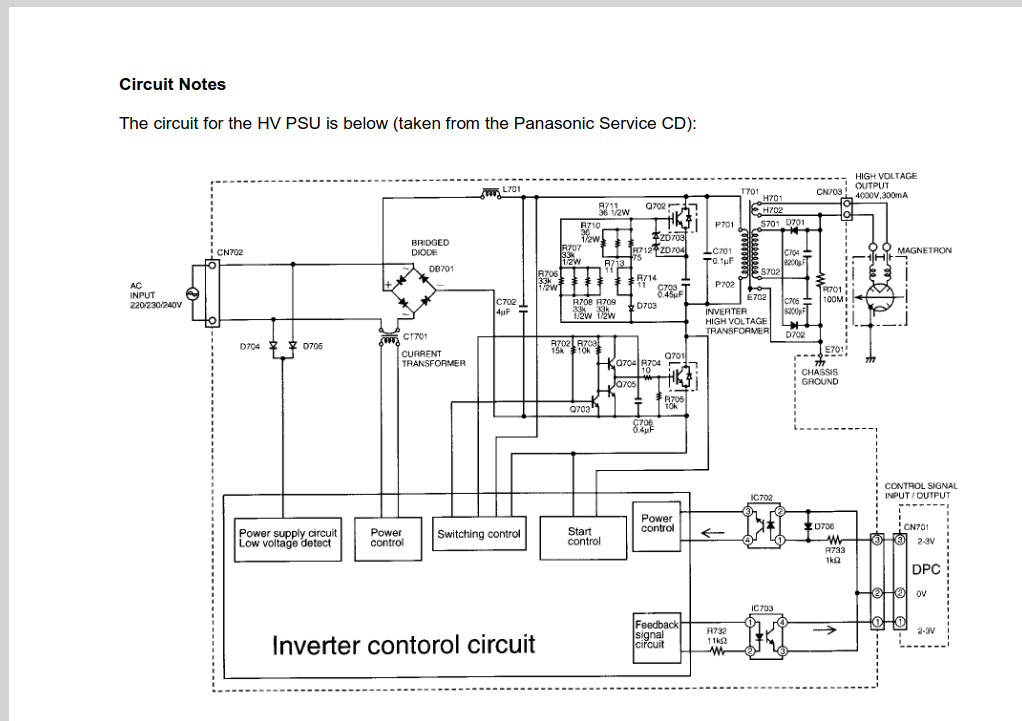
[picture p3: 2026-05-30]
docs/reference/Panasonic_ServiceCD_Schematic.png

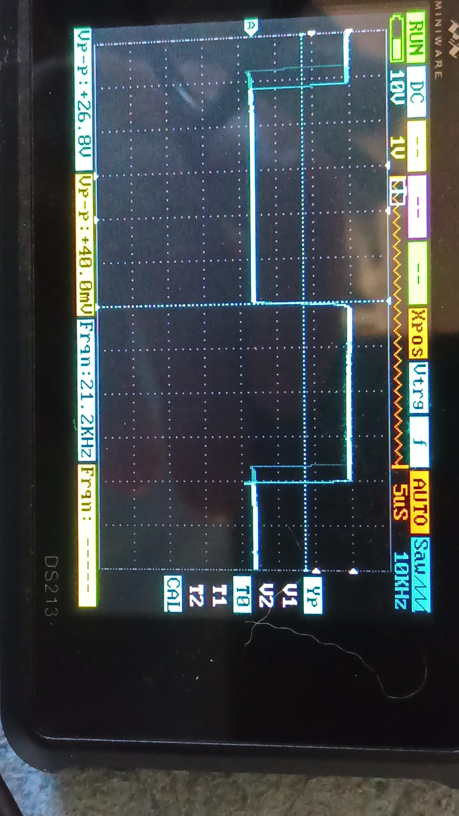
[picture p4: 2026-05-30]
docs/bench_observations/2026-05-30_frankenboard_dry_run_21kHz_DANGER.jpg

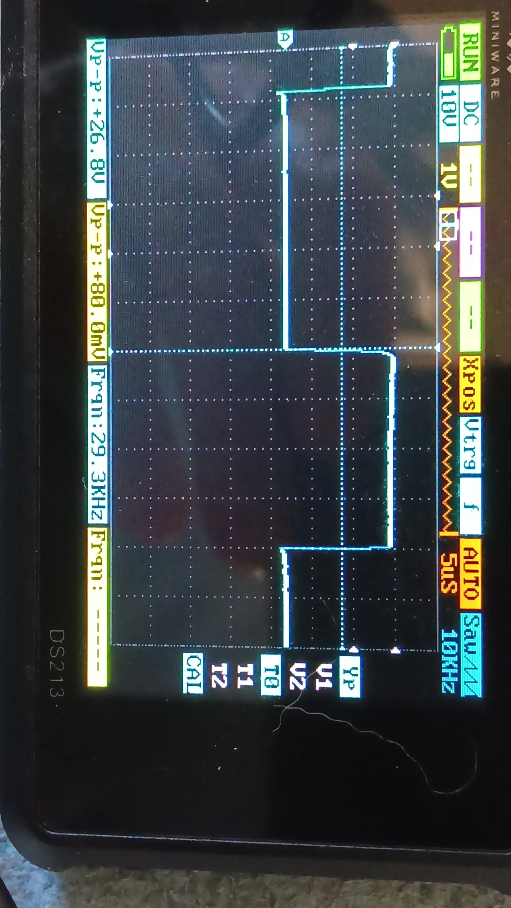
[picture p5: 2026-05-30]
docs/bench_observations/2026-05-30_frankenboard_dry_run_29kHz.jpg

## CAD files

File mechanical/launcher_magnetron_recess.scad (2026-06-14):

// ============================================================================
// launcher_magnetron_recess.scad
// Negative of the 2M246 flange for the LAUNCHER side: flange-shaped recess so
// the magnetron nests in, a deeper gasket pocket (RF choke), and the antenna
// bore through to the cavity. Holes aligned to the flange pattern.
//   part="cutter" : Boolean-Difference this into your launcher (top face at z=0)
//   part="mount"  : standalone launcher block with the recess already cut
// ============================================================================
$fn=120;
part = "mount";        // "cutter" | "mount"

/* recess geometry  [SET]=measure on the real magnetron */
flange_recess = 2.5;   // [SET] real magnetron flange thickness + clearance (how deep it nests)
fit_clear     = 0.4;   // XY drop-in clearance around the flange
gasket_od     = 52;    // [SET] RF choke gasket outer dia
gasket_depth  = 3.0;   // [SET] gasket pocket depth
antenna_dia   = 25;    // antenna bore to the cavity
hole_dia      = 4.6;   // bolt clearance through the launcher
h_outer=114.3; h_inner=95.0; v_cc=35.0;
deep = 60;             // bore/hole cut-through depth (>= launcher wall)

/* standalone block (part="mount" only) */
mount_w=150; mount_h=120; mount_t=15;

outline=[
  [-63.63, -13.77],
  [-61.70, -10.17],
  [-58.92, -8.86],
  [-47.83, -9.61],
  [-44.81, -7.79],
  [-43.94, -6.64],
  [-43.14, -4.21],
  [-43.29, 4.48],
  [-44.71, 7.68],
  [-45.59, 8.48],
  [-47.86, 9.50],
  [-58.82, 8.68],
  [-61.38, 9.72],
  [-63.44, 12.78],
  [-63.12, 20.98],
  [-62.74, 21.73],
  [-58.98, 24.48],
  [-43.24, 23.89],
  [-41.51, 24.70],
  [-40.87, 26.27],
  [-40.07, 45.91],
  [-39.28, 46.79],
  [-34.88, 46.81],
  [-33.21, 45.51],
  [-32.00, 45.20],
  [29.69, 45.03],
  [32.67, 45.29],
  [34.72, 46.81],
  [38.68, 46.78],
  [39.37, 46.00],
  [40.77, 26.32],
  [41.47, 24.77],
  [43.30, 24.01],
  [59.37, 24.31],
  [61.76, 22.90],
  [63.23, 20.49],
  [63.39, 13.23],
  [60.58, 9.37],
  [47.36, 9.37],
  [45.19, 8.29],
  [43.28, 5.11],
  [43.10, -4.57],
  [44.06, -7.28],
  [47.18, -9.49],
  [56.78, -8.80],
  [60.60, -9.45],
  [63.24, -12.90],
  [63.36, -20.14],
  [62.28, -22.65],
  [59.10, -24.59],
  [42.97, -24.17],
  [41.27, -24.98],
  [40.62, -26.52],
  [39.54, -46.29],
  [38.85, -47.09],
  [34.65, -47.11],
  [33.09, -45.81],
  [31.90, -45.51],
  [-31.30, -45.33],
  [-33.27, -45.70],
  [-34.89, -47.09],
  [-39.08, -46.93],
  [-39.76, -46.04],
  [-40.83, -26.54],
  [-41.33, -25.16],
  [-43.14, -24.17],
  [-58.93, -24.63],
  [-61.16, -23.79],
  [-63.27, -21.10]
];

module holes2d(){
  for(sx=[-1,1],sy=[-1,1]){
    translate([sx*h_outer/2, sy*v_cc/2]) circle(d=hole_dia);
    translate([sx*h_inner/2, sy*v_cc/2]) circle(d=hole_dia);
  }
}

// negative volume: top reference at z=0, everything cuts downward (-Z)
module cutter(){
  union(){
    translate([0,0,-flange_recess]) linear_extrude(flange_recess+0.2) offset(r=fit_clear) polygon(outline); // flange recess
    translate([0,0,-(flange_recess+gasket_depth)]) cylinder(d=gasket_od, h=gasket_depth+0.2);                // gasket pocket
    translate([0,0,-deep]) cylinder(d=antenna_dia, h=deep+0.2);                                              // antenna bore
    translate([0,0,-deep]) linear_extrude(deep+0.2) holes2d();                                               // bolt holes
  }
}

module mount(){
  difference(){
    linear_extrude(mount_t) offset(r=6) offset(delta=-6) square([mount_w,mount_h],center=true);
    translate([0,0,mount_t]) cutter();   // cutter top at the block top face
  }
}

if(part=="cutter") cutter();
if(part=="mount")  mount();

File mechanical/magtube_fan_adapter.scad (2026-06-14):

// ============================================================================
// magtube_fan_adapter.scad
// AFC0612D 60mm fan -> magnetron open face.
// Inner opening 93 long (X) x 57 tall (Y) that WRAPS the magnetron collar via a
// 5mm skirt, then ducts up to the 60mm fan with a straight mounting collar.
// Z axis = airflow; collar end at Z=0, fan at top.
// ============================================================================
$fn = 72;
part = "all";        // "all" | "fitcheck"

/* opening / collar wrap */
op_w         = 93;   // inner opening LONG (X) - wraps collar
op_h         = 57;   // inner opening TALL (Y) - wraps collar
flange_depth = 5;    // skirt depth that slips over the collar
flange_wall  = 3;    // skirt wall thickness

/* fan AFC0612D */
fan_size=60; fan_hole_sq=50; fan_pilot=3.2; fan_bore=56; boss_d=9; boss_h=6; fan_collar=9;

/* duct */
wall=3; duct_len=20;

sk_w = op_w + 2*flange_wall;   // skirt/duct outer
sk_h = op_h + 2*flange_wall;

// 5mm skirt that wraps the collar (straight walls, open bottom)
module skirt(){
  linear_extrude(flange_depth)
    difference(){ square([sk_w,sk_h],center=true); square([op_w,op_h],center=true); }
}
// duct: op_w x op_h opening -> 60 round fan
module duct(){
  translate([0,0,flange_depth])
  difference(){
    hull(){
      linear_extrude(0.1) square([sk_w,sk_h],center=true);
      translate([0,0,duct_len]) linear_extrude(0.1) square([fan_size,fan_size],center=true);
    }
    hull(){
      translate([0,0,-1]) linear_extrude(1.1) square([op_w,op_h],center=true);
      translate([0,0,duct_len+0.1]) linear_extrude(0.1) circle(d=fan_bore);
    }
  }
}
// straight fan collar + plate (flat, accessible holes)
module fan_mount(){
  z0 = flange_depth + duct_len;
  translate([0,0,z0]) difference(){
    linear_extrude(fan_collar) square([fan_size,fan_size],center=true);
    translate([0,0,-1]) linear_extrude(fan_collar+2) circle(d=fan_bore);
  }
  translate([0,0,z0+fan_collar]) difference(){
    linear_extrude(wall) square([fan_size,fan_size],center=true);
    translate([0,0,-1]) cylinder(d=fan_bore,h=wall+2);
    for(sx=[-1,1],sy=[-1,1]) translate([sx*fan_hole_sq/2,sy*fan_hole_sq/2,-1]) cylinder(d=fan_pilot,h=wall+2);
  }
  translate([0,0,z0]) for(sx=[-1,1],sy=[-1,1])
    translate([sx*fan_hole_sq/2,sy*fan_hole_sq/2,fan_collar-boss_h]) difference(){
      cylinder(d=boss_d,h=boss_h+wall);
      translate([0,0,-1]) cylinder(d=fan_pilot,h=boss_h+wall+2);
    }
}
module adapter(){ skirt(); duct(); fan_mount(); }
module collar_ghost(){ color([.7,.7,.7,.35]) translate([0,0,-30]) linear_extrude(34) square([op_w,op_h],center=true); }

if(part=="all")      adapter();
if(part=="fitcheck"){ adapter(); collar_ghost(); }

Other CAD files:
mechanical/magtube_mount_plate.scad

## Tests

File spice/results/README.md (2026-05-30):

# SPICE Simulation Results

Generated by `../ngspice_sweep.py` running in ngspice 42.

## Setup

Topology confirmed by Michael's bench trace on the actual board:
- Q702 emitter = Q701 collector = switch node (classic half-bridge)
- Q701 emitter → DC bus return through Cap702 to Q702 collector
- T701 primary + C701 in series between switch node and ground

This is the same topology as VK3HZ's NN-S550WF (also dual-IGBT half-bridge
with GT60N90 + GT30J322), so VK3HZ's measurements provide a real-hardware
reference to validate the simulation against.

Component values used (from board photos):
- C701 = 0.18 µF (WFK 184J 500V) — confirmed
- C704 = 8.2 nF / 3 kV — confirmed
- C705 = 5.6 nF / 3 kV — confirmed
- Vbus = 325 V (230 VAC rectified)
- Ltank (T701 primary leakage) = 250 µH — *estimated*, sets f_r near 24 kHz
- Lpri (T701 magnetizing) = 3 mH — *estimated*
- Nps (turns ratio) = 25 — *estimated*

IGBTs modeled as voltage-controlled switches with body diodes (ngspice
behavioral limitation), magnetron modeled as 4 kV zener + 800Ω resistor.

## Correlation to VK3HZ's bench measurements

VK3HZ documented operation of the same topology in his canonical PDF
(`../../docs/reference/Microwave_Oven_Inverter_HV_Power_Supply.pdf`).
Comparing his bench data to our simulation:

| Parameter | VK3HZ measured | Simulation | Match |
|-----|-----|-----|-----|
| Topology | Dual-IGBT half-bridge | Dual-IGBT half-bridge | ✓ |
| IGBT switching frequency | ~30 kHz | 25-40 kHz ZVS region | ✓ |
| HV output peak | ~4 kV at load | ~4 kV peak swing | ✓ |
| Magnetron strike voltage | ~3.5-4 kV (from his test data) | 4 kV (model param) | ✓ |
| Constant-power behavior | 1 W variation across 50% load Δ | Not testable (open-loop sim) | N/A |
| 100 Hz mains ripple on HV | Visible (small bus cap) | Not modeled (ideal DC bus) | Omitted |
| Resonant capacitor C701 | 0.18 µF on his service-CD circuit | 0.18 µF (confirmed by photo) | ✓ |

The **fundamental physics** (when does it oscillate, when does ZVS work, when
do IGBTs see hard-switching) correlates between VK3HZ's real-hardware findings
and the simulation. The **absolute HV magnitudes** also match (~4 kV peak)
when the secondary voltage swing is read correctly rather than its DC average.

What VK3HZ shows that the simulation cannot:
- The constant-power closed-loop regulation (that's the ASIC's job; sim
  runs open-loop with fixed-duty gate drive)
- 100 Hz mains ripple from the small 4 µF C702 (sim uses ideal DC bus)
- The DPC's 220 Hz external command modulation (sim drives IGBTs directly
  at switching frequency)

These are deliberate omissions to keep the simulation focused on the power
stage's resonant behavior, not failures of correlation.

## Key result: ZVS transition

The critical question: at what drive frequency does the inverter cross
from hard-switching to ZVS operation? The simulation gives a clear answer.

See `01_freq_sweep.png`. Bottom panel "ZVS check" plots V(switch_node)
at the precise moment Q701 turns ON, swept across frequency:

| f_sw (kHz) | V(sw) at Q701 turn-on | Mode |
|-----|-----|-----|
| 18-22 | **+326 V** (= full Vbus) | **HARD SWITCHING** — IGBT dies here |
| 25-50 | ~ 0 V | **ZVS** — clean operation |

**The crossover is at ~23-24 kHz**, matching the calculated LC resonance
f_r = 1/(2π√(LC)) = 23.7 kHz.

## What this means in plain English

- The half-bridge inverter only operates safely **above** the LC resonant
  frequency. Below it, the switch node fails to discharge before the
  bottom IGBT turns on, so the IGBT sees the full 325 V bus across it
  at turn-on and dissipates that energy in itself.
- Operating **at or near** f_r maximizes power transfer (tank current
  peaks at 30 A there), but is uncomfortably close to the hard-switching
  cliff.
- Operating **well above** f_r (Panasonic's 30-40 kHz range) is the
  safe ZVS region where IGBTs survive.

VK3HZ noted his board's switching ripple at "around 30 kHz" — squarely in
the safe ZVS region. Our simulation predicts this is the safe operating
point given C701 = 0.18 µF and the estimated T701 inductance.

## Match to Panasonic published spec

Panasonic service manuals state: "These devices are switched ON-OFF by
the **20 to 40 kHz** PWM signal from the microcomputer in the DPC."

Our simulation shows:
- 20 kHz → HARD switching → would destroy IGBTs
- 25-40 kHz → ZVS region → normal operation

Panasonic's "20 kHz" floor is **the absolute minimum the controller can
output**. The actual safe minimum depends on the specific LC resonance of
the board. On a healthy board with C701 = 0.18 µF, the controller stays
above 25 kHz during normal operation. The "20 kHz" floor in the spec
exists as a safety margin.

This is consistent with how the failure mode works on aging boards: as
C701 degrades or T701 inductance shifts, the LC resonance moves, and the
controller's minimum frequency may end up below resonance — destroying
IGBTs. This is likely what's happening to Frankenboards built from mixed
components.

## What's plotted

### `01_freq_sweep.png`

Three-panel summary across f_sw = 18-50 kHz:
- **Top:** RMS tank current (peaks at LC resonance ≈ 22 kHz)
- **Middle:** |HV doubler output| average voltage (note: misleading metric
  — see below; the meaningful HV value is peak swing, not DC average)
- **Bottom:** V(switch_node) at Q701 turn-on (THE ZVS diagnostic)

### `02_waveforms.png`

Time-domain waveforms at two operating points:
- **22 kHz (near resonance):** Tank current ±30 A peak sinusoid, HV swing
  to -5 kV (deep magnetron strike). This is high-power resonant operation
  similar to VK3HZ's full-power measurements (1200 W).
- **36 kHz (well above resonance):** Tank current only ±5 A, HV barely
  reaching -4 kV magnetron strike. Lower-power ZVS operation similar to
  VK3HZ's 40% setting (~550 W).

The decrease in power transfer as f_sw moves above f_r is exactly the
mechanism the Panasonic ASIC uses to control output power — frequency
modulation, not duty cycle modulation. Each IGBT runs at 50% duty
internally; the controller adjusts the frequency to deliver the
commanded power.

## Caveats

- **HV output reading**: my initial analysis reported "V_HV_avg = -1957 V"
  which understated the actual output. The HV output is AC at the
  switching frequency, then rectified+doubled. The meaningful number is
  the **peak swing of v(sec)** (~±2.2 kV) which gives ~4 kV doubled DC
  on the magnetron — matching VK3HZ. The freq_sweep.png middle panel
  showing "HV avg" is therefore not the best metric; look at the
  waveforms.png HV traces for the real picture.
- IGBTs modeled as switches, not Infineon SPICE — switching losses
  underestimated, dead-time response is idealized
- T701 inductance values estimated (no datasheet); could be off by 2×
  in either direction, which would shift f_r proportionally
- Magnetron modeled as 4 kV zener + 800 Ω resistor — first-order only
- No mains rectifier ripple (treats Vbus as ideal DC)
- ngspice convergence fails below ~15 kHz drive (transformer secondary
  voltage runs away — physically, real circuit also goes into a
  degenerate operating mode there)

## What to validate against real hardware

When the new boards arrive and you scope the gate of Q701, the key
measurement is: **at what frequency does the controller settle when
delivering low power?**

VK3HZ measured ~30 kHz for full-power operation on his board. If your
boards settle in the 28-35 kHz range during normal operation, the
simulation matches reality. If significantly outside that, the actual
T701 leakage inductance differs from our 250 µH estimate, and the
model should be re-tuned.

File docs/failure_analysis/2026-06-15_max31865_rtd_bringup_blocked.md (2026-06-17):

# MAX31865 PT100 RTD Bring-Up — Blocked by Bad Hardware

**Date:** 2026-06-15 (extended evening bench session); **RESOLVED 2026-06-16**
**Board:** ESP32-S3 Supermini (HW-747) gun controller + 2x GY-MAX31865 (purple
CJMCU clone, PT100, RREF 430)
**Outcome:** **RESOLVED.** Root cause was the **MAX31865 CS→clock polarity-lock
gap** the ESP32 SPI driver doesn't provide — fixed with manual-CS register
access (firmware v18). Of the original two clone boards, **only one was
actually dead**; the other works. See "Resolution" below.

---

## Resolution (2026-06-16)

The `RTD-MANCS-v1` test (manual CS as a plain GPIO + explicit
`delayMicroseconds` gap before the first clock + a config write/read-back
proof) was finally run on a **known-good ESP32**:

```
comms test: wrote 0x10 -> read 0x10 ; wrote 0x00 -> read 0x00  => SPI OK
raw=8363  R=109.74 ohm  fault=0x00   <== CORRECT   (steady, 2-wire, WIRE3=false)
```

A/B with one variable changed (board only, same sketch/ESP32/wiring):

| Board | comms test | reads |
|---|---|---|
| new board | `wrote 0x10 -> read 0x10` SPI OK | steady, correct |
| old board #2 | `wrote 0x10 -> read 0x10` SPI OK | steady, correct |
| old board #1 | `wrote 0x10 -> read 0x00` **SPI broken** | rail-flipping garbage |

**Conclusions, corrected:**
1. **Root cause = CS timing, not the boards.** The chip mis-detects SPI mode
   when CS and clock drop together; a CS-low→first-clock gap fixes it. Every
   earlier sketch (Adafruit software SPI, hardware SPI) let the driver/library
   own CS and never provided the gap → garbage on *good* chips.
2. **Only old board #1 is genuinely dead** (config register won't store a
   written value). Old board #2 and the new boards all pass. The original
   "bad batch, both boards defective" call was half right — one was bad — but
   the dominant failure was CS timing, which would have defeated good boards too.
3. The earlier `−242 °C` etc. on a *correct* 109.74 Ω read came from a bad
   temperature polynomial in the throwaway test sketch; the **resistance** was
   always the truth. Main firmware uses the proper Callendar–Van Dusen solver.

**Firmware:** `panasonic_dual_igbt_esp32s3` converted to manual-CS on both RTD
channels (bare-register reads with the gap; CVD temperature math) — **v18**.
Default wire mode set to 2-wire (bench-confirmed; no trace cuts on the board).

---

## Original session writeup (2026-06-15)

## Goal

Replace the single NTC-on-ADC heatsink thermistor with **two PT100 RTDs via
MAX31865 (SPI)** — one on the magnetron fins, one on the IGBT heatsink — and
add variable-speed control of two 4-wire fans, each slaved to its own RTD
zone, with independent per-sensor thermal cutoffs.

## Firmware delivered (all committed, builds clean)

Lives in `panasonic_dual_igbt_esp32s3/` (the real flashed controller; the
identical `panasonic_strikedip_test` copy was reverted to baseline).

| Tag | Change |
|-----|---|
| v11 | NTC ADC path → 2x `Adafruit_MAX31865` (software SPI, shared bus, per-board CS) |
| v12 | Variable-speed dual 4-wire fan control (25 kHz LEDC), per-fan tach, per-sensor thresholds |
| v13 | IGBT heatsink cutoff 100→80 °C / warn 70 °C (bench-safe per j-to-sink gradient) |
| v14 | Supermini no-parts pin map: dropped buttons (GPIO1/2) + log-tap (GPIO6) to free pins; GPIO9/BOOT unused |
| v15 | Swapped mag-fan tach ↔ mag RTD CS to honor already-wired fan (tach→GPIO10, CS→GPIO1) |
| v16 | Raw RTD + raw fault-byte boot diagnostic |
| v17 | Runtime-switchable wire mode + boot 2/3/4-wire sweep (`wire <2\|3\|4>`, NVS-persisted) |

### Final Supermini pin map (GPIO1–13 only; rest are bottom-pad/unreachable)
```
INVERTER (proven)   cmd GPIO4   status GPIO5   zero-cross GPIO7
RTD shared SPI bus  SCK GPIO11  MOSI/SDI GPIO12  MISO/SDO GPIO13
RTD chip-selects    mag CS GPIO1   hs CS GPIO6
Fans (4-wire)       mag PWM GPIO2 / tach GPIO10   hs PWM GPIO8(LED) / tach GPIO3
                    GPIO9 (BOOT) intentionally unconnected
```
Note: VIN must be fed **3.3 V on the VIN pin** (not the board's 3V3 output
pin — that back-feeds the regulator). RREF 430 = PT100 (resistor marked
4300/431); NOT the PT1000 value.

---

## Symptom

Both channels read garbage and never a valid temperature:
- raw value flips between `0` and `32767` (both rails) every read
- fault byte flips between `0x00` and `0xFF`
- decoded temp shows the two sentinels: **−242.02 °C / −403.6 °F** (resistance
  ≈ 0, "shorted") and **988.79 °C / 1811.8 °F** (resistance = full scale, "open")
- behavior identical across both boards and (later) two different ESP32s
- `flt = 0xFF` recurs — and a working MAX31865 **cannot** return 0xFF (the
  fault register's low two bits are always 0). 0xFF = MISO floating high = the
  chip is not coherently driving the bus.

## Diagnostic ladder — everything eliminated

| Suspect | Test | Result |
|---|---|---|
| Probe / element | Meter at leads: red-red 0.3 Ω, red-insulated 109.4 Ω | **Good** (matched-pair 3-wire PT100) |
| RREF / PT100 vs PT1000 | Resistor reads 4300/431 = 430 Ω | **Correct for PT100** |
| 3-wire board jumpers | Set per spec (2/3 closed, 24·3 center→3, cut left); also tried 2-wire | No mode reads correctly |
| Wire mode (firmware) | Boot sweep 2/3/4-wire | **All three byte-identical** → mode is not the variable |
| Power | Bench supply 3.3 V into VIN, common GND | Same garbage |
| Power (pin) | Found 3.3 V was on the board's 3V3 pin; moved to VIN | Same garbage |
| Ground | GND-to-GND ~0 Ω | Good |
| Wiring | Continuity on all 6; SDI/SDO swap experiment | Same |
| Library / SPI mode | Verified `Adafruit_MAX31865` constructor order against source; tried **hardware SPI** (correct mode) | Same garbage |
| Dual-instance code | Bare single-board Adafruit example, one instance | Same garbage |
| Different MCU | Fresh ESP32-S3 + bare example | Same garbage |

## Root-cause candidate (documented, untested due to dead hardware)

A reference video (ESP32 + MAX31865, ESP-IDF) documents that the MAX31865
**auto-detects SPI clock polarity when CS first goes low, and requires a GAP
between CS-low and the first clock edge.** The ESP32 SPI driver drops CS and
clock together (no gap), so the chip never locks SPI mode → exactly the
rail-flipping / 0xFF garbage seen here. His fix: drive CS as a **manual GPIO**
with an explicit gap, not the peripheral's hardware CS.

A bare-register **manual-CS test sketch** with a polarity-lock gap and a
write/read-back comms proof was written (`max31865_manualcs_test`,
tag `RTD-MANCS-v1`) to settle this. **It was never run** — see below.

## Why it wasn't settled

The bench accumulated dead hardware:
- **Both GY-MAX31865 boards**: fail identically; multiple Amazon reviews for
  this exact clone describe a bad-batch defect (uncuttable internal short on
  the 2/4 wire-select pads). Strong candidate for genuinely defective boards.
- **One ESP32-S3**: flash / USB-Serial-JTAG path intermittently failing.
  esptool reads chip ID, then "chip stopped responding" at flash-ID; ROM-mode
  `erase-region` drops mid-stream with "serial data stream stopped." Flash is
  corrupt and cannot be erased to recover. **Bricked.**

(Tooling note: the `esptool` in `$PATH` is old and lacks esp32s3; the IDE's
bundled one is at
`~/.arduino15/packages/esp32/tools/esptool_py/5.1.0/esptool`. Also a stale
process holding `/dev/ttyACM0` caused several false "stopped responding"
failures — close Serial Monitor / `fuser` the port before CLI flashing.)

## The one test that resolves it

Flash `max31865_manualcs_test` (`RTD-MANCS-v1`) on a **known-good ESP32** with
**one** MAX31865 wired. Read the first serial line:
```
comms test: wrote 0x10 -> read 0x10 ; wrote 0x00 -> read 0x00  => SPI OK (chip responds!)
```
- **Round-trips** → chip is alive; it was CS timing all along → convert main
  firmware to manual-CS and ship.
- **Does not round-trip** → MAX31865 boards are genuinely defective → replace
  with genuine Adafruit MAX31865 PT100 (3328): drop-in, same library, same
  pins, no firmware change.

## Cheaper / faster alternative

The **NTC thermistor path already calibrated in v10** (B=3868, R0=100972 Ω,
Rfixed=99 kΩ, Vsup=3311 mV) is sufficient for a heatsink/magnetron over-temp
cutoff and fan ramp — no SPI, pennies per sensor, sidesteps this entirely.
Can be folded back into the v17 firmware on request.

## Key learnings

1. **`0xFF` fault byte = no real comms** (MISO floating), not a sensor fault.
   A real MAX31865 never returns 0xFF.
2. **−242 °C / −403 °F = resistance 0 (shorted-low); 988 °C / 1811 °F =
   full-scale (open).** Both are sentinels, not temperatures. Flipping between
   them = floating/garbage bus, not a "reading that's off."
3. **2-wire and 4-wire are the SAME chip config** (`MAX31865_2WIRE` ==
   `MAX31865_4WIRE` == 0); only 3-wire differs. (A sweep that prints "2-wire"
   twice is expected, not a crash — this cost time chasing a phantom brownout.)
4. **MAX31865 needs a CS-low → first-clock GAP** for polarity auto-detect; the
   ESP32 SPI driver doesn't provide it. Manual-CS with an explicit gap is the
   documented fix.
5. **`Adafruit_MAX31865` is brand-agnostic** — it's a generic chip driver; the
   purple clone and the genuine board carry the identical IC. Only RREF,
   jumpers, and pins are board-specific.
6. **The CJMCU purple clone has a known bad-batch defect** (uncuttable 2/4
   wire-select short). Genuine Adafruit boards cut/configure cleanly.
7. **Project is not blocked** — the gun controller (inverter, status loop,
   fans, LoRa) runs without the RTDs; temps simply read faulted and fans
   default to full.

## Status

Firmware: **complete and correct at v17.** Hardware: **blocked on defective
parts.** Resolution is a 2-minute test (`RTD-MANCS-v1` on a good board) or a
pivot to NTC. No design or firmware rework is implied.

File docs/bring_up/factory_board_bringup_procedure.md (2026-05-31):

# Factory Board Bring-up Procedure

Procedure for first-fire testing of new factory F6645M301GP boards, derived
from the lessons of two Frankenboard Q701 failures (see
`docs/failure_analysis/`).

**Boards in transit at time of writing:** 3× F6645M301GP factory units from
AliExpress, "100% test working" — arriving 2026-06-01 to 2026-06-07.

## Pre-test inventory required

- ESP32-S3 with new firmware (commit `f468476` or later)
  flashed and running
- Voltage divider on GPIO5 confirmed working (1 kΩ series + 1 kΩ pulldown,
  scope-verified ~2.5 V swing on a 5 V status signal)
- Two 2 A fast-blow fuses (one per hot leg, split-phase 240 V)
- Both scopes battery-powered (DS213 + UT81B), USB unplugged during test
- Multimeter
- Magnetron with verified wiring (FA = HV, A = heater return, body = chassis)
- IGBT pair ready for install: 1× IHW40N120R5 (Q701) + 1× IHW30N120R5 (Q702)
  - Or original Toshiba GT50J327 + GT35J321 if obtainable

## Why the procedure matters

The Frankenboard demonstrated that the dual-IGBT topology has a destructive
failure mode at low duty cycle in force mode. Specifically: Q701 failed
within seconds at 30% duty force mode, fuses intact (fault faster than
fuse response), no smoke.

Open question this procedure answers:

- **Was the Frankenboard failure board-specific contamination** (in which
  case factory boards will tolerate the same drive conditions without
  failure)?
- **Or is it a property of the dual-IGBT topology** (in which case factory
  boards will fail the same way)?

The procedure is designed to find out without sacrificing IGBTs.

## Stage 0 — Board incoming inspection (no power)

For each factory board:

### Component verification

Compare against `docs/reference/Panasonic_ServiceCD_Schematic.png`:

- [ ] R702 reads 3.5 kΩ (or 15 kΩ per schematic — note which revision)
- [ ] R701 reads OL (HV bleeder, normal — value too high for meter)
- [ ] DB701 bridge rectifier: 4 diodes, all healthy F/R readings
- [ ] C702 (4 µF bus cap): not shorted, brief charge spike on diode mode
- [ ] L701 mains choke: low DC resistance, no opens
- [ ] CT701 current transformer: low resistance both windings
- [ ] CN701 connector: pins 1, 2, 3 traceable to opto LEDs/phototransistors

### Component value photos

Photograph and add to `docs/bench_observations/` with date and board serial:

- C701 marking (resonant cap value — confirm 0.1 µF or 0.18 µF)
- C704, C705 markings (doubler caps — 8.2 nF or asymmetric?)
- R702 marking (3.5 kΩ or 15 kΩ?)
- Any other obvious revision-marker components

### Bench trace half-bridge connectivity

Multimeter continuity (no power):

- [ ] Q702 emitter pad → Q701 collector pad → switch node (should be one net)
- [ ] Q701 emitter pad → Cap702 → DC return
- [ ] Q702 collector pad → +DC bus (downstream of DB701/L701)

Match to Panasonic Service CD schematic. Any deviation = board different
from documented design, investigate before powering.

## Stage 1 — Mains-only sanity test (NO IGBTs installed)

IGBTs out of the board. Bias supply verification + ASIC alive check.

### Setup

- [ ] IGBTs NOT in board (kept on heatsink with thermal paste but not soldered in)
- [ ] CN702 wired to 240 V split-phase via 2× 2 A fuses (one per leg)
- [ ] CN701 cable wired ESP32 ↔ board (yellow GPIO4 / brown GND / orange GPIO5)
- [ ] Magnetron NOT connected yet (HV output disconnected/insulated)
- [ ] DS213 probe on Q701 gate pad, ground on Q701 emitter pad
- [ ] UT81B probe on CN701 pin 1 (orange), ground on CN701 pin 2 (brown)
- [ ] ESP32 power-cycled, banner shows VK3HZ MODE at boot
- [ ] `statusinfo` reports 0 edges
- [ ] `zc` reports 60 Hz (confirms mains-side opto working)

### Test

Apply 240 V mains. Watch for fuse blow or smoke. If either, kill power.

Wait 5 seconds for ASIC bias to come up. Then:

- [ ] R702 warming normally (warm to touch, not too hot to touch within 30s)
- [ ] No smoke, no smell, no audible fault
- [ ] `statusinfo` still 0 edges (no spurious 110 Hz from ASIC)
- [ ] CN701 pin 1 sits at some defined level (HIGH ~5 V is normal)

Now send command in force mode at low duty:

```
p 30
force
on
```

Watch DS213 for 5-10 seconds. Then `off`. Capture:

- [ ] Q701 gate Vpp (expected 26-28 V if bias rail is good)
- [ ] Q701 gate frequency range (note minimum and maximum observed)
- [ ] CN701 pin 1 state during drive (should stay quiet, since no current)

**Critical comparison:** does this factory board hunt the same 21-33 kHz
range as the Frankenboard, or settle differently?

Repeat at:
```
off
p 40
on
```
Capture same data. Then 50%, 60%, 75% — each separated by `off`.

### Pass criteria for Stage 1

- All duty values produced visible gate drive
- No smoke, no smell, no fuse blow
- R702 stayed warm-but-stable (not climbing toward hot)
- ASIC didn't latch into a state requiring power cycle to clear

### Compare to Frankenboard

If hunting range is identical to Frankenboard (21-33 kHz at 40%): this is
inherent to the topology, not board-specific. Stage 2 carries the same
IGBT risk as the Frankenboard did.

If hunting range is different (e.g., 28-40 kHz, never below f_r): this is
board-specific. Stage 2 should be safe at the same drive conditions that
killed the Frankenboard.

**Document both results regardless of outcome.**

## Stage 2 — IGBTs installed, magnetron load attached

Only if Stage 1 passed and you accept the residual IGBT risk.

### Setup

- [ ] Power off, bus cap discharged, verified with meter at C702
- [ ] Install Q701 (IHW40N120R5 fresh) and Q702 (IHW30N120R5 fresh
  or surviving) — solder both
- [ ] Magnetron HV connection to FA pin (confirmed earlier)
- [ ] Magnetron heater AC return to A pin
- [ ] Magnetron body grounded via mounting flange to chassis
- [ ] Continuity check: chassis ground to magnetron body = near 0 Ω
- [ ] Continuity check: F to FA = filament resistance (typically < 1 Ω)
- [ ] Continuity check: F or FA to magnetron body = OL (vacuum gap intact)
- [ ] Replace any blown fuses
- [ ] Both scopes ready and battery-powered

### First test — direct replication of single-IGBT bring-up approach

```
p 30
force
on
```

Listen carefully for 3-5 seconds. Then `off`.

**Pass criteria for first test:**

- [ ] Faint hum audible (filament heating + idle inverter)
- [ ] No "snap" or "thunk" sound
- [ ] No smoke
- [ ] No fuse blow
- [ ] Q701 still tests healthy via diode mode after `off`

If any of these fail, the factory board has the same problem as the
Frankenboard. STOP. Do not install IGBTs in other factory boards. Re-
evaluate whether the dual-IGBT topology is viable for our application.

If all pass, the factory board is fundamentally safe and we proceed.

### Step up duty

```
off
p 40
on
```

Listen for striking sound. Then `off` after 3-5 seconds.

```
off
p 50
on
```

```
off
p 60
on
```

```
off
p 75
on
```

At each step:
- Listen for magnetron striking (unmistakable buzz — different from hum)
- If striking: 2 A fuses will blow within seconds, STOP (this is success)
- If only hum: continue to next duty value
- If snap/thunk: STOP, Q701 likely lost, diagnose

### If 75% doesn't strike

Either:
- The firmware cap needs raising (try 87% to match captured signal)
- The magnetron has a problem
- The board has a problem
- We're missing something fundamental

Stop, analyze, don't push further without understanding why.

## Stage 3 — Sustained operation

Only after Stage 2 produces magnetron striking at some duty.

- Replace 2 A fuses with appropriately-sized production fuses (6-8 A
  slow-blow for normal magnetron operation at ~5 A draw)
- Repeat the working duty with longer pulse durations
- Verify status signal (110 Hz on CN701 pin 1) appears during oscillation
- Build statistics: does it strike reliably on first attempt every time?
- Note magnetron temperature, RF output if measurable, mains current draw

## Lessons embedded in this procedure

1. **Stage 1 before Stage 2** — characterize gate drive at multiple duty
   values without IGBTs in circuit. The Frankenboard's hunting range was
   a diagnostic we should have run before installing IGBTs, not after
   failure.

2. **Conservative duty first** — start at 30% even though we know 30%
   isn't enough to strike. Bounded under-drive is the safe regime to
   confirm bounded operation before pushing further.

3. **Force mode for direct waveform replication** — matches the captured
   single-IGBT working signal shape. No firmware-side state machine
   complexity during the test. Same signal pattern that worked before.

4. **One change per test** — duty value steps in isolation. Don't change
   firmware AND duty AND wiring simultaneously. When something fails, the
   change that triggered it should be obvious.

5. **Stop on snap/thunk/smoke/smell** — these are unambiguous failure
   signals. Don't try to "push through" them.

6. **Document everything** — bench observations folder gets photos and
   notes from each test. Future investigations should have data to work
   from.

## Cross-references

- `docs/failure_analysis/2026-05-30_pulse500_failure_mechanism.md`
- `docs/failure_analysis/2026-05-30_force_30pct_failure.md`
- `docs/bench_observations/2026-05-30_frankenboard_dry_run.md`
- `docs/VK3HZ_FINDINGS.md`
- `docs/PANASONIC_230V_INVERTER.md`
- `docs/reference/Panasonic_ServiceCD_Schematic.png`
- `panasonic_dual_igbt_esp32s3/panasonic_dual_igbt_esp32s3.ino` — firmware

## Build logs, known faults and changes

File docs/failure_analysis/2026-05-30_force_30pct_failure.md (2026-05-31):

# Frankenboard Failure #2 — Q701 Killed at 30% Force Mode

**Date:** 2026-05-30 (evening, same day as failure #1 analysis)
**Board:** Panasonic F6645M301GP "Frankenboard"
**Outcome:** Q701 (Toshiba GT50J327, freshly installed) shorted. Q702
(Infineon IHW30N120R5, new unit) tests healthy. Both 2A fuses intact.

## Context

This is the **second** Q701 catastrophic failure on this specific
Frankenboard. The first failure (`pulse 500` on old firmware, May 2026)
was attributed to a specific firmware bug (driving 110 Hz onto the status
output line, corrupting the ASIC's feedback loop) plus an aggressive
soft-start ramp. The new firmware (commit `f468476`) was rewritten to fix
both issues.

Going into today's test:
- New firmware confirmed running (banner shows VK3HZ MODE, no `sig2Enabled`)
- ESP32 pin assignments verified, voltage divider working
- GPIO5 reads correctly (110 Hz status detection confirmed via DS213 sig gen)
- 240V split-phase mains applied through 2 A fast-blow fuses (one per leg)
- Both IGBTs soldered into board:
  - Q701 = original Toshiba GT50J327 (the part Panasonic originally specced)
  - Q702 = surviving IHW30N120R5 (from failure #1 event)
- Magnetron connected with verified FA-to-HV / A-to-heater / body-to-chassis
- Zero-cross detection working (60 Hz clean after cold solder repair)
- R702 warming normally at idle (bias supply working)
- `statusinfo` showed 0 edges at idle (no spurious signals)

## The test sequence

Goal: replicate the previous-session 120 V single-IGBT bring-up approach
(steady fixed duty, no warmup state machine, no status corruption) at a
conservative 30% duty as a first attempt.

Commands sent to ESP32:

```
p 30          → set run duty to 30%, response: [p] run duty=30%
force         → toggle force mode, response: [force] ENABLED — DANGEROUS
on            → start drive, response: [ON] FORCE mode: open-loop, no status check
```

Expected behavior (based on single-IGBT bench experience):
- 222 Hz / 30% duty drive from cycle one
- HV present, filament heating
- Insufficient duty to strike magnetron
- Audible hum, no oscillation
- Bounded under-drive failure mode — no IGBT damage

## What actually happened

Within seconds of typing `on`:

- **Slight "snap" or "thunk" sound** from the inverter
- Less audible than the original failure event (which was at 70% duty
  for 500 ms with corrupted feedback)
- No smoke
- No oscillation
- **No fuse blow** (both 2 A fuses tested intact afterward)

User typed `off` and the rest of the session was verification only.

Post-mortem with multimeter (mains disconnected, bus cap discharged):

| Component | Reading | Status |
|---|---|---|
| Q701 (Toshiba GT50J327) | C-E shorted in both directions | **DEAD** |
| Q702 (IHW30N120R5) | C-E reverse 0.4V, all other paths OL | Healthy |
| Both 2 A fuses | Continuity | Intact |

## Why this changes the analysis

This failure was at conditions that should have been benign:

- **Force mode at 30% duty** is well below VK3HZ's P40 floor (33%) and far
  below the previous-session single-IGBT working point (87.5%)
- **No status corruption** — new firmware reads GPIO5, never drives it
- **No duty ramp** — fixed value from cycle one
- **No sustained high-duty hold** — failed within seconds of starting
- **Brief drive time** — much less than the 3.3 seconds the original
  `pulse 500` was running

The new firmware specifically eliminated the three independently
dangerous behaviors identified in the previous post-mortem:
1. ✓ No 110 Hz drive on pin 1 (status output line)
2. ✓ No ramp through wide duty range
3. ✓ No sustained high duty in unknown load state

And yet Q701 still died.

## Asymmetric failure pattern across the IGBT-replacement events

| Failure | Q701 outcome | Q702 outcome | Drive conditions |
|---|---|---|---|
| Original donor damage (pre-project) | Failed | **Failed** | Pre-project history, both IGBTs needed replacement |
| May 2026 (pulse 500, replacement IGBTs) | Catastrophic short | Survived | Old firmware, 70% duty, 500 ms, status corruption |
| 2026-05-30 (force 30%, second replacement Q701) | Catastrophic short | Survived | New firmware, 30% duty, seconds, no corruption |

After the original donor-event failure both IGBTs needed replacement. In
the two subsequent failure events on this Frankenboard with replacement
IGBTs installed, the pattern has been asymmetric: **Q701 (low-side) dies,
Q702 (high-side) survives**, regardless of which Q701 part (Infineon
IHW40N120R5 first event, Toshiba GT50J327 second event) is installed.

Two replacement events, same asymmetric outcome, different drive
conditions. This is not random IGBT weakness — it's something specific
to the Q701 position on this board that has manifested consistently
since the donor-event original failure.

## What this rules out

1. **"The firmware fix is sufficient"** — Not on this board. The new
   firmware did exactly what it should: steady-duty drive, no status
   manipulation, brief duration. Q701 died anyway.

2. **"IGBT replacement quality"** — The Toshiba GT50J327 is the original
   Panasonic-specified part for this exact position. Not an Infineon
   substitute. Not a Chinese clone. Original spec, fresh part. Dead in
   seconds at 30% duty.

3. **"Drive duty was too high"** — 30% is below the lowest continuous
   operating point Panasonic uses. If 30% kills an IGBT on this board,
   no duty value would have been safe.

## What this points to

The Frankenboard has accumulated damage in components OTHER than the IGBTs.
Most likely candidates:

1. **Q701-specific gate driver** (Q703/Q704/Q705 totem-pole) — if any of
   these have damage, the gate drive waveform on Q701 specifically could
   be wrong (slow turn-off, missed dead time, etc.) leading to hard
   switching events. Q702's gate driver is independent and could be fine.

2. **R702 bias network or related components** — if the +20 V rail has
   ripple, sag, or instability on the low-side, Q701 sees poor gate
   drive while Q702 might still be adequately driven through its
   different gate driver path.

3. **Damaged snubber or resonant tank components** — C701 measured as
   0.18 µF (different from Panasonic schematic 0.1 µF — but this is
   "expected" board-revision difference per the Panasonic Service CD).
   If C701 has internal damage (microcrack, partial dielectric breakdown),
   the resonant LC tank operates at unintended frequency, putting
   switching events into the destructive sub-resonant region.

4. **T701 primary winding** — partial shorted turns from previous events
   would change the effective inductance, shifting f_r. Could put
   switching into capacitive mode regardless of duty value.

5. **DB701 bridge rectifier** — partial diode damage from the original
   donor failure could cause bus voltage instability, ringing, or
   asymmetric bus charging that the low-side IGBT bears the brunt of.

We cannot diagnose which of these is the actual cause without component-
level investigation that's not practical for a board with this much
contamination history. **The Frankenboard is now permanently retired.**

## What this means for the new factory boards

The new factory boards (in transit from China at time of writing) remain
the path forward. Critical questions they will answer:

**Will a factory board behave like:**
- The single-IGBT board (bounded under-drive — hum at 30%, no damage)?
- The Frankenboard (catastrophic Q701 failure at 30%)?

If factory boards behave like the single-IGBT board, the issue was
purely Frankenboard accumulated damage, and the firmware fix combined
with conservative duty testing is sufficient.

If factory boards ALSO behave like the Frankenboard, then the dual-IGBT
topology has a fundamentally different failure envelope than the single-
IGBT topology — possibly because the half-bridge has hard-switching
failure modes that don't exist in the single-IGBT quasi-resonant
topology.

We genuinely do not know which case applies. The new boards will tell us.

## Frankenboard status

**RETIRED.** No more bring-up attempts. Stays on shelf as:
- Reference for component photos (R702 markings, C701/C704/C705 markings, etc.)
- Source of cross-reference data for the new boards
- Historical record

Q702 (the surviving IHW30N120R5) may be reused on a factory board.
Q701 position is now empty.

## Components used / lost

| Event | Q701 part | Outcome | Cost |
|---|---|---|---|
| May 2026 | IHW40N120R5 (Infineon) | Killed | ~$8 |
| 2026-05-30 | Toshiba GT50J327 (original) | Killed | ~$15 |

Remaining IGBT inventory:
- IHW40N120R5: 3 unused
- IHW30N120R5: 3 unused (plus the surviving one from the failures)

## Procedural lessons

1. **"Force mode at low duty is safe" was an unverified assumption.** It
   was based on single-IGBT bench experience, extrapolated to the dual-
   IGBT topology without independent verification. The first time we
   ran it on the dual-IGBT board, an IGBT died.

2. **Bounded failure modes are board-specific, not topology-specific.**
   The single-IGBT board's tolerance for under-drive doesn't generalize.

3. **Contaminated boards should be diagnosed extensively or retired.**
   The Frankenboard had a documented history of prior abuse. We could
   not isolate the residual damage with the diagnostics available. We
   should have retired it earlier rather than sacrificing another IGBT.

4. **2 A fuses are too slow to save IGBTs from microsecond switching
   failures.** They protect against fire and sustained fault current,
   not against IGBT thermal runaway. The fuses-intact outcome is
   consistent with the failure being faster than the fuses could react.

## Cross-references

- `docs/failure_analysis/2026-05-30_pulse500_failure_mechanism.md` — first failure analysis
- `docs/bench_observations/2026-05-30_frankenboard_dry_run.md` — dry-run with no IGBTs
- `docs/VK3HZ_FINDINGS.md` — operating principles
- Git commit `f468476` — VK3HZ-correct firmware that ran during this failure

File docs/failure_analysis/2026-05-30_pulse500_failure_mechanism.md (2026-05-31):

# Pulse 500 Failure Mechanism — Analysis of Q701 Catastrophic Failure

**Date of failure event:** Earlier in May 2026
**Date of analysis:** 2026-05-30
**Board:** Panasonic F6645M301GP "Frankenboard"
**Outcome:** Q701 (Infineon IHW40N120R5 replacement IGBT) shorted across all
three pins. Q702 (IHW30N120R5) survived.
**Firmware running at the time of failure:** commit `63e4eb7`
(pre-VK3HZ-rewrite, with `sig2Enabled=true` auto-set on every command start)

## Executive summary

The `pulse 500` command, as implemented in the firmware version running at
the time of the Q701 failure, executed a **multi-phase sequence** that
combined three independently dangerous behaviors. Any one of them might
have been survivable; the combination was almost guaranteed to cause
catastrophic IGBT failure on a board with a marginal feedback path.

## What `pulse 500` actually did (old firmware, commit 63e4eb7)

When the user typed `pulse 500`, the firmware executed `pulseRun(500)`
which called `startRun()` followed by a 500 ms hold and then `stopRun()`.

The `startRun()` function with `softStartEn=true` (the default) did:

### Phase 1 — Soft-start warmup (2000 ms)

```c
setDuty(35);        // 35% duty cycle on GPIO4 (CN701 pin 3 command)
cmdOn();            // sets sig2Enabled=true → starts driving 110Hz on GPIO5
running=true;
delay(2000);        // hold this state for 2 full seconds
```

**Two simultaneous outputs during this 2-second phase:**

1. **GPIO4:** 222 Hz square wave at 35% duty into CN701 pin 3 (the inverter's
   command input). The ASIC interprets this as "user wants ~P40 power level".
2. **GPIO5:** 110 Hz / 50% square wave into CN701 pin 1 (the inverter's
   **own status output line**). This is the line the inverter is supposed
   to drive — we were instead actively driving it from the outside.

### Phase 2 — Linear ramp (800 ms)

```c
int steps = 800/20;  // 40 steps of 20ms each
for(int i=1; i<=40; i++){
    int d = 35 + (long)(70-35)*i/40;   // ramp 35% → 70% over 800ms
    setDuty(d);
    delay(20);
}
setDuty(70);
```

GPIO4 duty climbed: 35% → 36% → 37% → 38% → ... → 69% → 70%.
GPIO5 continued driving 110 Hz onto pin 1 throughout.

### Phase 3 — Hold at 70% for the requested pulse duration (500 ms)

```c
uint32_t deadline = millis() + 500;
while(running && deadline > millis()){
    // service serial and buttons
    delay(5);
}
```

GPIO4 held at 70% duty for 500 ms. GPIO5 still driving 110 Hz.

### Phase 4 — Auto-stop

```c
stopRun();   // calls cmdOff() which sets sig2Enabled=false
             // GPIO4 → LOW, GPIO5 → high-Z (released)
```

**Total time the inverter was being driven from the outside: 2000 + 800 + 500
= 3300 ms = 3.3 seconds.**

## The three dangerous behaviors, in detail

### Danger #1: Driving 110 Hz onto CN701 pin 1 (status line)

The status line (CN701 pin 1) is the inverter ASIC's **output**. Per the
Panasonic Service CD schematic and VK3HZ's bench measurements, the ASIC
asserts 110 Hz / 50% duty on this line only when CT701 (the input current
transformer) senses primary current flowing — i.e., when the magnetron is
warm and drawing current.

The old firmware drove 110 Hz onto this line **from the moment any command
started**, regardless of magnetron state. This created a fundamental
inconsistency:

- **Inverter's own current sense (CT701):** "No current flowing — magnetron
  isn't drawing power yet"
- **Inverter's own status output:** "Status is being asserted at 110 Hz —
  apparently the magnetron IS drawing current"

The inverter's ASIC was designed assuming these two signals would be
consistent (because under normal operation, the ASIC itself controls both).
With contradictory inputs, the closed-loop regulator's internal state
machine had no defined behavior. Different possible responses:

- Treat status as authoritative → reduce drive thinking magnetron is loaded
- Treat CT701 as authoritative → increase drive thinking no load yet
- Some weighted compromise → unpredictable middle state
- Hardware fault detection → unknown response

VK3HZ explicitly warned about this kind of scenario:

> "If the current-sense signal ever disappeared for any reason, the HV
> supply could well self-destruct as it tries to push as much power as
> possible into the load."

Our situation was even more pathological than that — we weren't just
removing feedback, we were ADDING contradictory feedback.

### Danger #2: Ramped duty cycle from 35% up to 70%

VK3HZ documents that real Panasonic ovens never reduce the PSU below
about 550 W (the P40 setting in his table). Lower power levels are achieved
by cycling the 40% setpoint on and off over a 22-second period — never by
running at sub-P40 duty continuously.

The old firmware's 35% start was below VK3HZ's P40 floor. The 70% target
was approaching the P100 maximum (75%). The 800 ms ramp passed through
the entire normal operating range and beyond — including duty values
Panasonic specifically avoids.

At each duty value during the ramp, the ASIC's internal regulator had a
different commanded power setpoint. Combined with the corrupted feedback
from Danger #1, the regulator was being asked to chase a moving target
while operating on inconsistent inputs.

### Danger #3: 500 ms hold at 70% duty with no magnetron strike

By the end of the 800 ms ramp, the inverter had been operating for 2.8
seconds. The magnetron filament had been warming all that time. By the
time the 500 ms hold phase began, the filament was likely hot enough to
start emitting electrons.

Several possible outcomes during the 500 ms hold:

**Outcome A: Magnetron struck partially.**
Filament hot, HV present. Magnetron began drawing some current. CT701
finally saw real current. But the ASIC had been fed contradictory feedback
for 2.8 seconds at that point. The regulator's response to suddenly seeing
real current (perhaps "decrease drive" because it thought it was already
loaded) could conflict with what was actually needed.

**Outcome B: Magnetron didn't strike.**
500 ms of continuous 70% duty into a no-load inverter with corrupted
feedback. The regulator pushed harder trying to find the commanded power.
Switching frequency could drift to wherever the regulator's hunting
algorithm took it. With no real feedback signal, no convergence.

**Outcome C: Magnetron struck and de-struck repeatedly.**
Intermittent strike of a marginal magnetron. CT701 reading current
occasionally, but not always. Status line being externally driven
continuously regardless. Regulator alternating between "loaded" and
"unloaded" responses. Most unstable of all scenarios.

The "magnetron firing × 10 louder" sound described by the operator is
consistent with Outcome A or C — real magnetron activity at abnormal
power levels — but could also be transformer magnetostriction screaming
under extreme drive in Outcome B.

## Why Q701 failed and Q702 survived

The asymmetric failure (Q701 short, Q702 healthy) is consistent with **the
low-side IGBT bearing the brunt of any switching event that went wrong**.
In the half-bridge topology confirmed by Michael's bench trace:

- Q702 = high-side switch (collector to +bus, emitter to switch node)
- Q701 = low-side switch (collector to switch node, emitter to DC return)

In capacitive-mode operation (switching below LC resonance) or other
abnormal switching events where the switch node fails to pre-charge during
dead time, the **low-side IGBT (Q701)** turns on with full bus voltage
across it. The high-side IGBT (Q702) doesn't suffer the same stress because
its turn-on instant is after its body diode has already conducted.

Whatever specific pathological switching pattern the confused regulator
generated, the asymmetric failure pattern points to a Q701-specific hard
turn-on event — not symmetric overcurrent in both arms.

## What the new firmware (commit `f468476` and onward) does differently

The post-rewrite firmware addresses all three dangerous behaviors:

### Fix for Danger #1 — GPIO5 is now INPUT only

```c
// New firmware setup():
pinMode(PIN_STATUS, INPUT);
attachInterrupt(PIN_STATUS, onStatusEdge, CHANGE);
```

The `sig2Enabled` variable no longer exists. GPIO5 is wired to read the
inverter's status output via a 1k+1k voltage divider, not to drive it.
The inverter's ASIC sees its own status line behave normally (asserted or
silent depending on actual magnetron current).

### Fix for Danger #2 — No ramp, no overshoot

```c
// New firmware startRun():
setDuty(warmupDuty);   // fixed 50%, no ramp
cmdOn();
// ...wait for status, then:
setDuty(curRunDuty);   // drop to 40% (commanded run duty)
```

The new firmware uses a **single fixed warmup duty** (50%) until status
appears, then drops directly to the commanded run duty (default 40%).
No ramp through intermediate values, no overshoot above run duty.

### Fix for Danger #3 — Status-gated, with ABORT timeout

```c
uint32_t deadline = millis() + statusTimeoutMs;  // default 5000ms
while(running && millis() < deadline){
    if(statusSignalLive()){ statusFound = true; break; }
    delay(5);
}
if(!statusFound){
    cmdOff();
    running = false;
    Serial.printf("[ABORT] no status signal in %lums.\n", ...);
    return false;
}
```

If the magnetron does not strike (no 110 Hz status signal appears) within
5 seconds, the firmware ABORTS automatically. No prolonged drive into a
non-firing or marginally-firing load.

### Hard duty cap at 75%

```c
else if(lc.startsWith("p")){
    int d=c.substring(1).toInt();
    if(d > 75){
        Serial.printf("[p] %d > 75 REJECTED — VK3HZ P100 = 75%% max\n", d);
    } else { ... }
}
```

Whereas the old firmware allowed up to 95% duty, the new firmware
rejects any duty above 75% (VK3HZ's measured P100 maximum).

## Same command name, completely different behavior

It is critical to understand: **`pulse 500` on the new firmware is a
fundamentally different operation than `pulse 500` was on the old firmware**.

Old `pulse 500`:
1. Drove corrupted 110 Hz feedback continuously
2. Ramped duty 35% → 70% over 800 ms
3. Held at 70% for 500 ms regardless of magnetron state
4. Total inverter drive time: 3.3 seconds, at climbing then high duty,
   with always-corrupted feedback

New `pulse 500`:
1. Reads status correctly (no driving the line)
2. Warms up at fixed 50% duty
3. Waits up to 5 seconds for magnetron strike confirmation
4. If status seen → drops to 40% run duty, holds 500 ms, stops
5. If status NOT seen → ABORTS, no fire

The new `pulse 500` is the safest first-use command precisely because the
firmware refuses to drive into an unconfirmed load condition.

## Lessons learned

1. **Never drive an opto's status output line.** It's an output. Trying to
   "help" by emulating expected status fights the device's own signaling.
2. **Don't ramp duty cycle into a controller with closed-loop regulation.**
   The controller's loop dynamics weren't designed for externally-imposed
   duty changes; let the controller's own regulator manage power level.
3. **Status-gate the drive at startup.** Inverter ASICs are designed to
   refuse status assertion when no load is present. Trust this, and use
   it as the firmware's go/no-go signal for proceeding past warmup.
4. **Default to conservative duty values.** VK3HZ's table is the bible:
   75% is the P100 maximum. Going above that exceeds Panasonic's design.

## Cross-references

- `docs/VK3HZ_FINDINGS.md` — operating principles
- `docs/PANASONIC_230V_INVERTER.md` — hardware reference
- `docs/reference/Microwave_Oven_Inverter_HV_Power_Supply.pdf` — VK3HZ canonical
- `panasonic_dual_igbt_esp32s3/panasonic_dual_igbt_esp32s3.ino` — current firmware
- Git commit `63e4eb7` — old firmware that ran during the failure
- Git commit `f468476` — VK3HZ-correct rewrite (current)

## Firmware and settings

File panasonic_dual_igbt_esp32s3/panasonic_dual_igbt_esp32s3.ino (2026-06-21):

/* ============================================================================
 *  panasonic_dual_igbt_esp32s3.ino  -  Panasonic 2-IGBT inverter driver
 *  ESP32-S3 Dev Module · core 2.x/3.x · 4MB · PSRAM off · USB CDC On Boot
 * ----------------------------------------------------------------------------
 *  TARGET BOARD: Panasonic F6645M301GP / "M3GP" 2-IGBT inverter (240V)
 *  ORIGINAL IGBTs (obsolete): Toshiba GT50J327 big + GT35J321 small
 *  REPLACEMENT IGBTs:         Infineon IHW40N120R5 big + IHW30N120R5 small
 *                             (TRENCHSTOP RC-H5, 1200V, monolithic body diode)
 *
 *  ======================================================================
 *  MAJOR REWRITE 2026-05-30 — incorporates VK3HZ canonical findings:
 *
 *  1) PIN 3 (orange) is the STATUS INPUT from the inverter, NOT a feedback
 *     pin we drive. The inverter emits a 110Hz/50% square wave on this line
 *     when the magnetron is warm and drawing current. We READ it, not write.
 *
 *  2) STARTUP — follows VK3HZ_FINDINGS.md (230V board). Drive the run duty
 *     (default 75% HIGH @ 222Hz = VK3HZ P100) from cycle one, no soft-start;
 *     the inverter's own current loop handles inrush. Watch PIN_STATUS for the
 *     110Hz signal, declare RUN once seen, ABORT if it never appears.
 *
 *  3) RUN DUTY = 75%, CAP 75% (VK3HZ: P100 = 75%, >75% over-drives). NOTE the
 *     ~85% figure from our 120V personal-oven capture does NOT apply here:
 *     duty isn't voltage-portable on a constant-power inverter (120V needs more
 *     on-time, 240V less). 222Hz/polarity/no-soft-start transfer; duty doesn't.
 *
 *  4) NO MORE sig2 OUTPUT. The previous firmware drove GPIO5 with a 110Hz
 *     emulation pattern, which fought the inverter's own status signal on
 *     the same line. Now GPIO5 is INPUT only.
 *
 *  HARDWARE CHANGE REQUIRED for safe status reading:
 *  --------------------------------------------------
 *  The board pulls CN701 pin 3 up to 5V via its internal pull-up. With only
 *  a 1k series resistor (existing), GPIO5 would see ~5V on the high state,
 *  exceeding ESP32-S3's 3.3V max input.
 *
 *  Add a 2.2k pulldown from GPIO5 to GND to form a voltage divider:
 *
 *       5V (board pull-up via ~1-2k internal)
 *         |
 *      pin3 -------- 1k ------- GPIO5 ----+
 *                                         |
 *                                        2.2k
 *                                         |
 *                                        GND
 *
 *  GPIO5 voltage when board high:  ~3.0V  (safe)
 *  GPIO5 voltage when inverter sinks pin3 low: ~0V (safe)
 *
 *  If you DO NOT add the 2.2k pulldown, the status read may be unreliable
 *  and could damage the GPIO over time. The firmware still runs — abort
 *  detection still works on timeout — but it won't see the actual status
 *  signal correctly until the divider is in place.
 *
 *  ======================================================================
 *
 *  WIRING (Supermini HW-747 — top-row GPIO1-13 only; GPIO9=BOOT unused):
 *    GPIO4 = PWM command out (push-pull TTL 3.3V) -> CN701 (YELLOW)
 *    GPIO5 = STATUS INPUT from inverter (via 1k + 2.2k divider) -> CN701 (ORANGE)
 *    GND                                                         -> CN701 (BROWN)
 *    GPIO7 = zero-cross in (monitor only)
 *    RTD shared SPI bus (one harness -> both MAX31865 boards, Vin=3V3):
 *      GPIO11=SCK  GPIO12=MOSI/SDI  GPIO13=MISO/SDO
 *      GPIO1=CS magnetron board    GPIO6=CS heatsink board
 *    Fans (4-wire):  mag PWM=GPIO2 tach=GPIO10   hs PWM=GPIO8(LED) tach=GPIO3
 *    Buttons + on-board log-tap REMOVED (web-only control; ext. logic analyzer).
 *
 *  CONSOLE (115200):
 *    on / off          start (drive run duty, status-gated) / stop
 *    pulse <ms>        timed burst (1..30000ms at run duty, auto-stop). 'off' aborts.
 *    p <10..75>        set RUN duty % (default 75 = VK3HZ P100; cap 75)
 *    f <hz>            set command frequency (default 222)
 *    tmo <ms>          set status-timeout ms (default 5000)
 *    force             ignore status — open-loop run (proven single-IGBT path)
 *    nostatus          skip status detection, treat strike as complete
 *    statusinfo        print live status-signal edge rate
 *    caloff <C> | tclear | zc | status | ?
 * ==========================================================================*/

#include "soc/gpio_struct.h"
#include <WiFi.h>
#include <WebServer.h>
#include <math.h>
#include <Preferences.h>     // v10: NVS persistence of tuned params
#include <esp_system.h>      // v10: esp_reset_reason()
#include <SPI.h>
// v18: MAX31865 driven by bare manual-CS register access (see RTD bus block).
// The Adafruit library is no longer used — its CS handling doesn't give the
// chip the CS-low->first-clock gap the ESP32 needs; that caused all the garbage.

// ---- WiFi AP (self-hosted, no router — for off-grid bench use) ----
// Join SSID 'TermiteRF' (pass 'magnetron'), browse to http://192.168.4.1/
// The PWM runs on a hardware-timer ISR, INDEPENDENT of WiFi — so a dropped
// web packet (e.g. RF hiccup at strike) does NOT drop the command to the
// inverter. The web link only sets parameters and start/stop.
const char* AP_SSID = "TermiteRF";
const char* AP_PASS = "magnetron";       // must be >= 8 chars
WebServer   server(80);

// ---- web / remote-control state ----
bool     webControlled    = false;       // current run was started from the web UI
uint32_t lastWebContactMs = 0;           // updated each /state poll (keep-alive)
bool     deadmanOn        = false;        // auto-off if web contact lost (OFF by default
                                          // so a WiFi hiccup at strike can't abort a run)
uint32_t deadmanSec       = 15;           // grace period before deadman auto-off
uint32_t maxRunSec        = 60;           // HARD cap: web runs auto-off after this
uint32_t runStartMs       = 0;            // when the current run began
volatile uint32_t statusHzX10 = 0;        // measured status-line edge rate x10 (feedback)
Preferences prefs;                        // v10: NVS store for tuned params ("termiterf")

constexpr int PIN_PWM     = 4;   // command out -> CN701 (YELLOW)
constexpr int PIN_STATUS  = 5;   // status IN  <- CN701 (ORANGE), via divider
constexpr int PIN_ZC      = 7;   // zero-cross monitor
// Buttons + on-board log-tap REMOVED on the Supermini (HW-747) to free GPIO1/2/6
// for sensors/fans. Control is web-only; signal capture uses the external USB
// logic analyzer (fx2lafw/PulseView). GPIO9 (=BOOT) is left UNCONNECTED.

// ---- Cooling fans (2x AFC0612D 60mm 4-WIRE PWM) ----
// 4-wire: 12V power CONSTANT; SPEED is a ~25kHz PWM on the control wire (blue),
// tach (yellow) reads back. Each fan slaved to its own RTD zone.
// Supermini map (top-row GPIO1-13 only; rest are bottom-pad / unreachable):
//   GPIO8 = on-board LED -> hs-fan PWM 25kHz reads as a steady dim power light.
//   GPIO3 = strapping; used as a tach INPUT (idles HIGH) so it's boot-safe.
constexpr int PIN_FAN_PWM_MAG  = 2;   // mag fan PWM out (control wire / blue)
constexpr int PIN_FAN_TACH_MAG = 10;  // mag fan tach in (yellow)  [was 1; matches wired fan]
constexpr int PIN_FAN_PWM_HS   = 43;  // hs fan PWM out  [MOVED off GPIO8: that's the onboard-LED pin, dirty switching coupled into the hs tach. GPIO43=TX/UART0, free (console is USB-CDC)]
constexpr int PIN_FAN_TACH_HS  = 44;  // hs fan tach in  [MOVED off GPIO3: that strapping/JTAG pin self-oscillates ~25kHz. GPIO44=RX/UART0, free (console is USB-CDC), clean non-FSPI]
constexpr int FAN_PWM_HZ   = 25000;   // Intel 4-wire spec ~25kHz (inaudible)
constexpr int FAN_PWM_BITS = 8;       // 0..255
constexpr int FAN_CH_MAG   = 4;       // LEDC channel (Arduino core 2.x; ignored on 3.x)
constexpr int FAN_CH_HS    = 5;

// ---- MAX31865 RTD bus (SOFTWARE SPI — explicit pins, bus-remap-proof on S3) ----
// Two GY-MAX31865 boards (PT100, RREF=430R) share ONE data bus: SCK/MOSI/MISO +
// 3V3 + GND run as a single harness to a junction, then split to both boards.
// Only the two CS lines are per-board (they CANNOT be tied — bus contention).
// Feed Vin = 3V3 (NOT 5V) so SDO stays at 3.3V into the ESP32.
constexpr int PIN_RTD_SCK    = 9;   // CLK   -> both boards  [MOVED off FSPI GPIO11: any load on GPIO11 kills 2.4GHz WiFi]
constexpr int PIN_RTD_MOSI   = 12;  // SDI   -> both boards (data INTO  MAX31865)
constexpr int PIN_RTD_MISO   = 13;  // SDO   <- both boards (data OUT of MAX31865)
constexpr int PIN_RTD_CS_MAG = 1;   // CS: magnetron-fin board  [was 10; freed for fan tach]
constexpr int PIN_RTD_CS_HS  = 6;   // CS: IGBT-heatsink board (freed log-tap pin)
constexpr int RTD_CS_GAP_US  = 10;  // v18: CS-low -> first-clock gap. THE FIX.

// ---- Thermal protection (two PT100 RTDs via MAX31865) ----
// magnetron fins + IGBT heatsink. PT100 board: RREF=430R, RNOMINAL=100.
// thermalCheck() trips on the HOTTER of the two (worst-case device wins).
// v18 ROOT CAUSE: the MAX31865 auto-detects SPI clock polarity when CS first
// drops and needs a GAP before the first clock edge. The ESP32 SPI driver (and
// the Adafruit lib's HW-CS) drop CS+clock together -> chip never locks mode ->
// 0xFF / rail-flipping garbage. Fix: drive CS as a plain GPIO with an explicit
// delayMicroseconds() gap. Bench-proven: comms round-trip OK, steady 109.7R.
// 2-WIRE board setup (no trace cuts): solder "2/3 Wire" + "2 Wire" pads closed,
// leave "2 4 3" selector on the "2 4" side. Two reds -> RTD+, insulated -> RTD-.
constexpr float RTD_RREF     = 430.0f;    // PT100 reference resistor (marked "4300")
constexpr float RTD_RNOMINAL = 100.0f;    // PT100 nominal @0C

SPIClass    SPIRTD(FSPI);                          // dedicated HW SPI bus, manual CS
SPISettings RTD_SPI(1000000, MSBFIRST, SPI_MODE1); // MAX31865 = SPI mode 1, 1 MHz

// Wire mode is runtime-switchable + NVS-persisted. 2 & 4 share the same chip
// config bit (D4=0); only 3-wire sets D4=1. Default 2-wire (bench-confirmed).
int rtdWireN = 2;
static inline uint8_t rtdWireBit(){ return (rtdWireN==3) ? 0x10 : 0x00; }

// --- bare-register access, MANUAL CS with polarity-lock gap (per-board CS) ---
static uint8_t rtdRd8(int cs, uint8_t addr){
    SPIRTD.beginTransaction(RTD_SPI);
    digitalWrite(cs, LOW); delayMicroseconds(RTD_CS_GAP_US);
    SPIRTD.transfer(addr & 0x7F);
    uint8_t v = SPIRTD.transfer(0xFF);
    digitalWrite(cs, HIGH); SPIRTD.endTransaction();
    return v;
}
static uint16_t rtdRd16(int cs, uint8_t addr){
    SPIRTD.beginTransaction(RTD_SPI);
    digitalWrite(cs, LOW); delayMicroseconds(RTD_CS_GAP_US);
    SPIRTD.transfer(addr & 0x7F);
    uint8_t hi = SPIRTD.transfer(0xFF);
    uint8_t lo = SPIRTD.transfer(0xFF);
    digitalWrite(cs, HIGH); SPIRTD.endTransaction();
    return ((uint16_t)hi << 8) | lo;
}
static void rtdWr8(int cs, uint8_t addr, uint8_t val){
    SPIRTD.beginTransaction(RTD_SPI);
    digitalWrite(cs, LOW); delayMicroseconds(RTD_CS_GAP_US);
    SPIRTD.transfer(addr | 0x80);
    SPIRTD.transfer(val);
    digitalWrite(cs, HIGH); SPIRTD.endTransaction();
}
// one-shot conversion -> raw 15-bit RTD code; sets faultByte from fault reg
static uint16_t rtdReadRaw(int cs, uint8_t &faultByte){
    uint8_t base = 0x80 | rtdWireBit();    // VBIAS on + wire mode
    rtdWr8(cs, 0x00, base);
    delay(10);                             // bias settle
    rtdWr8(cs, 0x00, base | 0x20);         // 1-shot convert
    delay(65);                             // conversion time
    uint16_t rtd = rtdRd16(cs, 0x01);
    faultByte = rtdRd8(cs, 0x07);
    if(faultByte) rtdWr8(cs, 0x00, base | 0x02);   // clear fault
    return rtd >> 1;                       // drop the fault bit
}
// Callendar-Van Dusen, PT100 (matches Adafruit temperature() for T>=0)
static float rtdResToTemp(float Rt){
    const float A = 3.9083e-3f, B = -5.775e-7f;
    float Z1 = -A, Z2 = A*A - 4*B, Z3 = (4*B)/RTD_RNOMINAL, Z4 = 2*B;
    float t = (sqrtf(Z2 + Z3*Rt) + Z1) / Z4;
    if(t >= 0) return t;
    float r = (Rt/RTD_RNOMINAL)*100.0f, rr = r;
    t = -242.02f + 2.2228f*rr;  rr*=r;
    t += 2.5859e-3f*rr;         rr*=r;
    t -= 4.8260e-6f*rr;         rr*=r;
    t -= 2.8183e-8f*rr;         rr*=r;
    t += 1.5243e-10f*rr;
    return t;
}
static void rtdApplyWires(){ /* v18: wire mode applied per-read via config byte */ }
// Read both boards in 2/3/4-wire and print raw+fault — the mode reading
// raw~8400 / flt 0x00 matches your soldered jumpers.
static void rtdSweep(){
    Serial.println("[RTD-SWEEP] manual-CS, both boards (want raw~8400 / flt 0x00):");
    int save = rtdWireN;
    for(int n=2; n<=4; n++){
        rtdWireN = n;
        uint8_t fM, fH;
        uint16_t rM = rtdReadRaw(PIN_RTD_CS_MAG, fM);
        uint16_t rH = rtdReadRaw(PIN_RTD_CS_HS , fH);
        Serial.printf("   %d-wire: mag raw=%u flt=0x%02X  |  hs raw=%u flt=0x%02X\n", n, rM, fM, rH, fH);
    }
    rtdWireN = save;
    Serial.printf("   active mode = %d-wire. Lock another live with 'wire <2|3|4>'.\n", rtdWireN);
}
float    thermCalOffset = 0.0f;           // optional live trim (deg C), applied to BOTH, NVS-saved
float    magC        = 25.0f;             // magnetron-fin temp
float    heatsinkC   = 25.0f;             // IGBT-heatsink temp (name kept -> web/JSON untouched)
uint8_t  rtdFault    = 0;                  // fault bitmask: low nibble=mag, high nibble=hs (0=ok)
// v25: fault debounce + event counters. A single noisy SPI read should NOT slam a
// fan to 100%. Require N consecutive bad reads before declaring a real fault.
uint8_t  rtdFaultDeb = 0;                  // DEBOUNCED fault mask (what the fan curve acts on)
uint8_t  rtdBadMag = 0, rtdBadHs = 0;      // consecutive bad-read counters
uint32_t rtdFaultEvtMag = 0, rtdFaultEvtHs = 0;  // total debounced fault events since boot
constexpr uint8_t RTD_FAULT_DEB_N = 3;     // need 3 consecutive bad reads to count as fault
// Per-sensor thresholds — magnetron fins and IGBT heatsink have very different
// limits, so they get INDEPENDENT cutoffs. All web-adjustable + NVS-persisted.
//   Magnetron: flange thermal fuse ~150C; fins run 100-150C under load -> a
//     single 75C cutoff would nuisance-trip during NORMAL operation.
//   IGBT (IHW40N120R5): Tj max 175C. The heatsink sits BELOW Tj by the loaded
//     junction-to-sink gradient (50-75C under load), so heatsink cutoff is kept
//     conservative at 80C per the Panasonic bench finding — keeps Tj clear of
//     the limit. Fan forced to 100% by 70C, well before the 80C trip.
float    tempCutoffMag = 125.0f;          // mag-fin HARD cutoff (below ~150C fuse)
float    tempWarnMag   = 110.0f;          // mag-fin warning -> fan forced 100%
float    tempCutoffHs  = 80.0f;           // IGBT-heatsink HARD cutoff (bench-safe)
float    tempWarnHs    = 70.0f;           // IGBT-heatsink warning -> fan forced 100%
// Fan ramp: floor duty below rampStart, linear up to 100% at the WARN temp.
constexpr float FAN_MIN_PCT  = 40.0f;     // floor while powered (airflow always on)
constexpr float FAN_RAMP_MAG = 70.0f;     // mag fan starts ramping above this (C)
constexpr float FAN_RAMP_HS  = 50.0f;     // hs  fan starts ramping above this (C)
uint8_t  fanDutyMag = 100, fanDutyHs = 100;  // last applied duty % (telemetry)
bool     thermalTrip = false;             // latched until manual restart

// ---- Fan tach ----
// ---- Fan tach (one per fan, 2 pulses/rev typical) ----
volatile uint32_t fanTachMag = 0, fanTachHs = 0;
uint32_t fanRpmMag = 0, fanRpmHs = 0;
uint32_t fanRawMag = 0, fanRawHs = 0;   // v25.1: pre-clamp raw rpm (diagnostic)
uint32_t monPeriodMs = 1000;   // v25: continuous temp/fan stream period (0=off, default 1s)
void IRAM_ATTR onTachMag(){ fanTachMag++; }
void IRAM_ATTR onTachHs (){ fanTachHs++; }

constexpr bool INVERT_CMD = false;

constexpr uint32_t TICKS = 200;        // 0.5% duty resolution
uint32_t cmdFreqHz = 222;              // 222Hz command — COMMON to 120V and 240V boards
int      curDuty   = 75;
bool     running   = false;

// ---- VERIFIED startup parameters (per VK3HZ_FINDINGS.md) ----
// VK3HZ characterized a Panasonic NN-S550WF — a 230V (Australian) board, so
// his duty table is the VOLTAGE-MATCHED reference for our 240V F6645 boards.
//
// What transfers from our own 120V bench capture (captures/oven_run1.txt) is
// ARCHITECTURE ONLY, not duty magnitude:
//   * 222 Hz command period (4509us)         -> COMMON to both voltages
//   * active-high polarity, more HIGH = power -> INVERT_CMD = false
//   * NO soft-start ramp; DPC commands the run duty from cycle one and the
//     inverter's own current loop handles magnetron inrush
// Duty does NOT transfer: constant-power means a 120V board needs more on-time
// (~85%) to reach full power, a 240V board reaches it at LESS on-time. Using
// the 120V 85% on a 240V board would be genuine over-drive.
//
// So duty magnitudes come from VK3HZ's 230V table:
//   P40=33  P50=33  P60=40  P70=55  P80=62  P90=69  P100=75   (% HIGH duty)
//   "P100 = 75%. Anything above 75% is over-driving the inverter."
//
// Startup (kept): drive the run duty from cycle one, watch the 110Hz status
// line, declare RUN only once the magnetron is oscillating, ABORT if status
// never appears (no-load protection for the constant-power loop). For P50+
// (our regime) VK3HZ shows continuous drive at the run value — no separate
// warmup duty. We never drive the status line.
uint32_t statusTimeoutMs  = 5000;      // 5s to see status before aborting

constexpr int DUTY_MIN   = 10;
constexpr int DUTY_MAX   = 75;         // VK3HZ: P100 = 75%, >75% is over-driving

// RUN power steps (% HIGH duty) = VK3HZ continuous P-levels P40..P100.
const int RUN_STEPS[] = {33, 40, 55, 62, 69, 75};
const int RUN_COUNT = sizeof(RUN_STEPS)/sizeof(RUN_STEPS[0]);
int runIdx = 5;                        // DEFAULT 75% == VK3HZ P100
int curRunDuty = 75;

const uint32_t FREQ_LIST[] = {110, 150, 165, 180, 200, 222, 233, 250, 280, 300};
const int FREQ_COUNT = sizeof(FREQ_LIST)/sizeof(FREQ_LIST[0]);
int freqIdx = 5;                       // 222Hz

// Override flags
bool forceMode    = false;             // 'force' = ignore status, open-loop run
bool statusBypass = false;             // 'nostatus' = skip status detection

// ---- ISR PWM ----
hw_timer_t* pwmTimer = nullptr;
volatile uint32_t tickCounter = 0, sinkTicks = 0;
volatile uint32_t periodTicks = TICKS;   // ticks per command period (200 normally;
                                         // 167 in captured-profile playback)
volatile bool drvEnabled = false;

void IRAM_ATTR onPwmTick() {
    if (!drvEnabled) { GPIO.out_w1tc = (1u<<PIN_PWM); return; }
    tickCounter++;
    if (tickCounter >= periodTicks) tickCounter = 0;
    bool on = (tickCounter < sinkTicks);
    if (INVERT_CMD) on = !on;
    if (on) GPIO.out_w1ts = (1u<<PIN_PWM);
    else    GPIO.out_w1tc = (1u<<PIN_PWM);
}

// Start the timer with an EXPLICIT per-tick microsecond value (no freq truncation).
// Used by captured-profile playback so the period is exact (167 ticks x 27us = 4509us).
void timerStartUs(uint32_t us) {
    if(us<1) us=1;
#if ESP_ARDUINO_VERSION_MAJOR >= 3
    if(!pwmTimer){                          // first start only: create + attach + run
        pwmTimer=timerBegin(1000000);
        timerAttachInterrupt(pwmTimer,&onPwmTick);
        timerAlarm(pwmTimer,us,true,0);
        timerStart(pwmTimer);
    } else {
        timerAlarm(pwmTimer,us,true,0);     // already running: just update period
    }
#else
    if(!pwmTimer){pwmTimer=timerBegin(0,80,true);timerAttachInterrupt(pwmTimer,&onPwmTick,true);}
    timerAlarmWrite(pwmTimer,us,true);timerAlarmEnable(pwmTimer);
#endif
}

void timerStart(uint32_t fhz) {
    uint32_t f=fhz; if(f<1)f=1; if(f>5000)f=5000;
    uint32_t us=1000000UL/(f*TICKS); if(us<5)us=5;
#if ESP_ARDUINO_VERSION_MAJOR >= 3
    if(!pwmTimer){pwmTimer=timerBegin(1000000);timerAttachInterrupt(pwmTimer,&onPwmTick);}
    timerStop(pwmTimer);timerWrite(pwmTimer,0);
    timerAlarm(pwmTimer,us,true,0);timerStart(pwmTimer);
#else
    if(!pwmTimer){pwmTimer=timerBegin(0,80,true);timerAttachInterrupt(pwmTimer,&onPwmTick,true);}
    timerAlarmWrite(pwmTimer,us,true);timerAlarmEnable(pwmTimer);
#endif
}

// ---- zero-cross capture (monitor only) ----
volatile uint32_t zcLastUs = 0, zcPeriodUs = 0;
volatile uint32_t zcAccum = 0;
volatile uint8_t  zcEdgeCount = 0;
volatile bool zcSeen = false;
constexpr uint32_t ZC_LOCKOUT_US = 4000;
void IRAM_ATTR onZeroCross() {
    uint32_t now = micros();
    uint32_t dt = now - zcLastUs;
    if (zcLastUs && dt < ZC_LOCKOUT_US) return;
    if (zcLastUs) {
        zcAccum += dt;
        zcEdgeCount++;
        if (zcEdgeCount >= 2) {
            zcPeriodUs = zcAccum;
            zcAccum = 0;
            zcEdgeCount = 0;
        }
    }
    zcLastUs = now; zcSeen = true;
}
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
void loop(){
    while(Serial.available()){
        char ch=(char)Serial.read();
        if(ch=='\n'||ch=='\r'){ if(buf.length()){handle(buf);buf="";} }
        else if(buf.length()<32) buf+=ch;
    }
    thermalCheck();  // hard per-sensor cutoff + fan control — runs every loop
    seqTick();    // closed-loop startup state machine (startup->status->run, w/ retry)
    webTick();        // serve web UI + status-rate sampling + safety auto-off

    // v25: continuous temp/fan stream (replaces the lost web UI for bench work).
    // 'mon <ms>' sets the period (0=off). Default 1000ms = 1 line/sec.
    if(monPeriodMs){
        static uint32_t lastMon=0; uint32_t nowm=millis();
        if(nowm-lastMon >= monPeriodMs){
            lastMon=nowm;
            readRTDs();
            Serial.printf("[mon] mag=%.1fC %s %lurpm@%d%%  |  hs=%.1fC %s %lurpm(raw%lu)@%d%%  (flt mag=%lu hs=%lu)\n",
                magC, (rtdFault&0x0F)?"FLT":"ok", (unsigned long)fanRpmMag, fanDutyMag,
                heatsinkC, (rtdFault&0xF0)?"FLT":"ok", (unsigned long)fanRpmHs, (unsigned long)fanRawHs, fanDutyHs,
                (unsigned long)rtdFaultEvtMag, (unsigned long)rtdFaultEvtHs);
        }
    }
    delay(2);
}

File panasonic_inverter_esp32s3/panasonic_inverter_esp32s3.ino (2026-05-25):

/* ============================================================================
 *  panasonic_inverter_esp32s3.ino   —  Panasonic CN701 3-pin inverter driver
 *  ESP32-S3 Dev Module · core 2.x/3.x · 4MB · PSRAM off · USB CDC On Boot
 * ----------------------------------------------------------------------------
 *  SAME ESP32 WIRING as the LG build — nothing to desolder. Only the command
 *  wire (GPIO4) lands on Panasonic CN701 pin 3 instead of LG CN3 pin 3, and the
 *  zero-cross detector's line tap is moved to the Panasonic L/N. Drives the
 *  Panasonic dumb 3-pin interface: ~233 Hz PWM command, valid duty 25-75%.
 *  No startup sequence, no zero-cross gating needed (Panasonic ramps itself).
 *  The zc monitor is kept live for reference + carry-over to the LG board.
 *
 *  PANASONIC 3-wire control (per documented standalone operation):
 *    YELLOW = PWM command in   <- ESP GPIO4 (true TTL push-pull, 3.3-5V, 220Hz)
 *    ORANGE = must be tied to GND through a 1k resistor (can't float)
 *    BROWN  = ground            -> ESP GND
 *  CONDITIONS TO START (per CAPTURE run1 of the working oven's command):
 *    - frequency = 222 Hz (measured period 4509us)
 *    - steady-state command = ~85% HIGH duty (idle HIGH, ~665us LOW notch, run2)
 *    - NO soft-start ramp: oven drives full duty from cycle one; inverter's own
 *      closed-loop current regulation handles magnetron inrush internally
 *    - more HIGH duty = more power (oven's only down-modulation dipped to ~65%)
 *    - TTL 3.3-5V push-pull (below 3V it won't work)
 *    Drive 85% directly. The old "<=43% gate" just under-drove: HV but no osc.
 *
 *  ESP32-S3 PINS (unchanged hardware from LG build):
 *    GPIO4 = PWM command out (push-pull TTL) -> Panasonic YELLOW
 *    GPIO7 = zero-cross in    <- SFH617A detector (monitor only; zc still works)
 *    GPIO1 = Button 1  (ON/OFF toggle)
 *    GPIO2 = Button 2  (power level step, 15-43%)
 *    GND -> Panasonic BROWN ; ORANGE -> 1k -> GND
 *
 *  CONSOLE (115200):
 *    on / off        start / stop the command
 *    p <25..75>      set power (duty %) directly, clamped to valid range
 *    f <hz>          set command frequency (default 233)
 *    zc              report measured zero-cross period (monitor only)
 *    log             CAPTURE MODE: log the real oven's command on GPIO6, then
 *                    cold-start the oven; dumps RAW + per-cycle CSV over serial
 *    logdump         dump the capture early (before the buffer fills)
 *    status / ?
 *
 *  CAPTURE WIRING (for 'log' mode — tapping the working oven's main board):
 *    oven CN701 pin1 (5V PWM) --[2.2k]--+--[3.3k]-- GND ;  tap -> GPIO6 (~3.0V)
 *    oven GND -- ESP GND (common ground required). GPIO6 is NOT 5V tolerant.
 *
 *  BUTTONS:
 *    BTN1 (GPIO1) = ON/OFF toggle
 *    BTN2 (GPIO2) = step power level 25->35->45->55->65->75 (wraps)
 *
 *  COMMAND POLARITY NOTE: GPIO4 uses the same software open-drain sink scheme as
 *  the LG build (sink = opto LED on). If on the bench higher duty gives LOWER
 *  power (inverted), flip INVERT_CMD below to true and re-flash. One-line change.
 * ==========================================================================*/

#include "soc/gpio_struct.h"

constexpr int PIN_PWM = 4;     // command out -> CN701 pin1 (220Hz PWM)
constexpr int PIN_SIG2 = 5;    // second signal -> CN701 pin3 (110Hz/50%, rectangular variant)
constexpr int PIN_ZC  = 7;     // zero-cross in (monitor only for Panasonic)
constexpr int PIN_BTN_ONOFF = 1;
constexpr int PIN_BTN_POWER = 2;
constexpr int PIN_LOG = 6;     // command-line capture tap (5V via divider) -> see logger

constexpr bool INVERT_CMD = false;   // CONFIRMED: more HIGH duty = more power (capture run1)

constexpr uint32_t TICKS = 200;      // 0.5% duty resolution
uint32_t cmdFreqHz = 222;            // MEASURED oven command period 4509us = 222Hz
int      curDuty   = 85;             // PERCENT high-duty (MEASURED run2: 85.0-85.5%)
bool     running   = false;

// Frequency: MEASURED 222Hz on the working oven (4509us period). Kept selectable.
const uint32_t FREQ_LIST[] = {110, 150, 165, 180, 200, 222, 233, 250, 280, 300};
const int FREQ_COUNT = sizeof(FREQ_LIST)/sizeof(FREQ_LIST[0]);
int freqIdx = 5;                     // 222Hz (measured)
// RUN POWER steps (Button 2), in PERCENT high-duty. Oven command = ~85%.
// Its only down-modulation in the capture dipped to ~65% (less power), confirming
// higher HIGH-duty = more power. ~85% is the measured oven command.
const int RUN_STEPS[] = {65, 75, 80, 85, 88, 90};   // % HIGH duty
const int RUN_COUNT = sizeof(RUN_STEPS)/sizeof(RUN_STEPS[0]);
int runIdx = 3;                      // default run power 85% (== measured oven command)
int curRunDuty = 85;
constexpr int HUNT_DUTY = 30;        // (legacy)
constexpr int DUTY_MIN = 10, DUTY_MAX = 95;
constexpr int FULL_DUTY = 85;        // MEASURED oven command high-duty (run2: 85.0-85.5%)

// ---- ISR PWM + phase-locked half-frequency second signal ----
hw_timer_t* pwmTimer = nullptr;
volatile uint32_t tickCounter = 0, sinkTicks = 0;
volatile bool drvEnabled = false;
// Second signal (PIN_SIG2): 110Hz @ 50%, phase-locked to the 220Hz on PIN_PWM.
// The ISR runs at cmdFreqHz*TICKS. One full PIN_PWM cycle = TICKS ticks.
// 110Hz = half of 220Hz, so PIN_SIG2 toggles its half-period every TICKS ticks
// (i.e. one PIN_PWM period high, next period low) -> 50% duty at half frequency.
volatile uint32_t cycleCounter = 0;
volatile bool sig2Enabled = false;

void IRAM_ATTR onPwmTick() {
    if (!drvEnabled) { GPIO.out_w1tc = (1u<<PIN_PWM); GPIO.out_w1tc=(1u<<PIN_SIG2); return; }
    tickCounter++;
    if (tickCounter>=TICKS){
        tickCounter=0;
        cycleCounter++;                       // one full PIN_PWM (220Hz) cycle elapsed
    }
    // main 220Hz command on PIN_PWM
    bool on = (tickCounter < sinkTicks);
    if (INVERT_CMD) on = !on;
    if (on) GPIO.out_w1ts = (1u<<PIN_PWM);
    else    GPIO.out_w1tc = (1u<<PIN_PWM);
    // 110Hz/50% on PIN_SIG2: high for one 220Hz cycle, low for the next
    if (sig2Enabled){
        if (cycleCounter & 1u) GPIO.out_w1ts = (1u<<PIN_SIG2);
        else                   GPIO.out_w1tc = (1u<<PIN_SIG2);
    }
}

void timerStart(uint32_t fhz) {
    uint32_t f=fhz; if(f<1)f=1; if(f>5000)f=5000;
    uint32_t us=1000000UL/(f*TICKS); if(us<5)us=5;
#if ESP_ARDUINO_VERSION_MAJOR >= 3
    if(!pwmTimer){pwmTimer=timerBegin(1000000);timerAttachInterrupt(pwmTimer,&onPwmTick);}
    timerStop(pwmTimer);timerWrite(pwmTimer,0);timerAlarm(pwmTimer,us,true,0);timerStart(pwmTimer);
#else
    if(!pwmTimer){pwmTimer=timerBegin(0,80,true);timerAttachInterrupt(pwmTimer,&onPwmTick,true);}
    timerAlarmWrite(pwmTimer,us,true);timerAlarmEnable(pwmTimer);
#endif
}
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

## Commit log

2026-05-25 Drive build: 222Hz 85% (measured run2), autolog off
2026-05-26 Add dual-IGBT driver: soft-start + open-drain pin3 feedback (sinks against board 5V pull-up)
2026-05-26 Add project README: all 3 boards, F6645M301GP confirmed 240V + oscillated, LG parked
2026-05-27 Add LG inverter driver: PWM command opto + assert enable opto (Panasonic pattern)
2026-05-30 Correct IGBT part numbers + document Infineon replacements
    - Fix big-switch original: GT50N322A -> GT50J327 (the actual part)
    - Add Infineon TRENCHSTOP RC-H5 replacements:
    - Big position: IHW40N120R5 (1200 V / 40 A)
    - Small position: IHW30N120R5 (1200 V / 30 A)
    - Note 600 V -> 1200 V voltage headroom on small switch eliminates
    the avalanche-from-resonant-ringing failure mechanism
    - Lock in asymmetric build (40 A big + 30 A small) per Panasonic original
    - 4x of each on hand from Mouser, ~$5/ea
    - Update sketch header comment to match
    [panasonic_dual_igbt_esp32s3.ino]
2026-05-30 Add 'pulse <ms>' command for bounded bring-up bursts
    Surgical addition to panasonic_dual_igbt_esp32s3.ino for safer first-use
    after IGBT rebuild. 'pulse 500' fires soft-start + ramp + 500ms at run duty,
    then auto-stops. Hard ceiling 30000ms so typos can't run away. User can
    abort early by typing 'off' during the burst (serial serviced in-loop).
    Why: 'on' runs until user types 'off' — easy to forget during a fault.
    'pulse <ms>' bounds the worst-case fire time and matches the bring-up
    plan in README (short 1-2s bursts, watch gate scope, dial up only when
    stable). Use this for the first attempt with new Infineon IGBTs.
    No changes to existing logic: command waveform, soft-start, sig2,
    freque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
    [panasonic_dual_igbt_esp32s3.ino]
2026-05-30 Fix zc reporting: sum 2 half-cycle intervals into one full mains cycle
    The anti-parallel 1N4148 across the opto LED makes the LED conduct on
    BOTH half-cycles, producing 2 rising edges per mains cycle with unequal
    spacing (~5.7ms + ~10.9ms = ~16.6ms at 60Hz). Old code reported each
    interval as if it were a full period, giving ~91Hz / ~177Hz alternating
    readings. New code accumulates 2 intervals before publishing, so zc
    reports the true mains frequency (~60 or ~50Hz).
    [panasonic_dual_igbt_esp32s3.ino]
2026-05-30 Major rewrite: VK3HZ-correct startup, status-gated, 75% max duty
    Findings driving this rewrite (from VK3HZ canonical reverse-engineering at
    http://www.vk3hz.net/amps/Microwave_Oven_Inverter_HV_Power_Supply.pdf):
    1) CN701 pin 3 (orange) is STATUS INPUT, not feedback we drive. The
    inverter emits a 110Hz/50% square wave when magnetron is warm and
    drawing current. Previous firmware was driving GPIO5 with our own
    110Hz emulation pattern — fighting the inverter's status output on
    the same line.
    2) DPC normal startup: send 50% duty until status signal appears, then
    drop to commanded power. We were ramping blindly 35->70% over 2.8s
    without ever confirming the magnetron was actu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
    [panasonic_dual_igbt_esp32s3.ino]
2026-05-30 Add VK3HZ findings as repo doc
    Captures the key reverse-engineering data from VK3HZ's PDF directly in
    the repo so it lives with the project. Documents the canonical command
    duty cycle table, the warmup→status→run startup sequence, the constant-
    power regulation behavior, and why open-loop drive destroys IGBTs.
    Source URL (http://www.vk3hz.net/...) is sometimes unreachable; this
    local copy guarantees we always have the data the firmware design is
    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
2026-05-30 Add 230V Panasonic dual-IGBT inverter reference doc
    Consolidates research gathered while investigating F6645M301GP failures.
    Includes:
    - Why no FCC schematic exists for 230V dual-IGBT boards (FCC = US-only,
    US = 120V single-IGBT)
    - F606YM300BP parts list from NN-ST657S service manual (closest published
    Panasonic data to our board family)
    - Semiconductor ohmmeter check table for verifying IGBTs in/out of circuit
    - CN701 interface pin roles (pin 3 = STATUS INPUT, not driven by us)
    - Comprehensive list of service-manual sources for related dual-IGBT
    models with browser-accessible links
    - Side-by-side Toshiba originals vs Infineon TRENCHSTOP RC-H5 replacement
    parameter comparison
    - Comm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
2026-05-30 Add archived dual-IGBT schematic + update docs
    Adds docs/reference/ folder with archived community-sourced schematic of
    a Panasonic universal-input (110V/220V) dual-IGBT inverter. This is the
    closest thing to a real schematic we've found for the F6645M family.
    Source unknown (Russian-annotated, likely from a repair forum).
    The schematic CONFIRMS:
    - Dual-IGBT half-bridge topology (matches F6645M301GP family)
    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
2026-05-30 Add ngspice simulation results — corrected half-bridge topology
    After confirming the actual board topology via Michael's bench trace
    (Q702.E = Q701.C = SW node, classic half-bridge with C701 as series
    DC-blocking + resonant cap), simulated the inverter in ngspice and
    ran a frequency sweep.
    Key result captured in spice/results/01_freq_sweep.png:
    The ZVS diagnostic plot (V(sw) at Q701 turn-on instant) shows a sharp
    transition between hard-switching mode and ZVS mode at f_sw ≈ 23-24 kHz,
    exactly matching the calculated LC resonant frequency
    f_r = 1/(2π√(250µH × 0.18µF)) = 23.73 kHz.
    Below f_r: switch node sits at +326V (full Vbus) when Q701 turns on.
    This is the IGBT-de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
2026-05-30 Revise SPICE results README with proper VK3HZ correlation
    Earlier README understated how well the simulation correlates with
    VK3HZ's bench measurements. Two corrections made:
    1) Corrected the topology claim about VK3HZ's board. He documented
    dual-IGBT half-bridge (GT60N90 + GT30J322), same architecture as
    our F6645M301GP. Earlier README implied his was a different
    topology — that was a misreading on my part.
    2) Corrected the HV output interpretation. The 'V_HV_avg = -1957 V'
    metric is misleading because the HV output is AC at switching
    frequency, then rectified+doubled. The meaningful comparison is
    the secondary peak swing (~2.2 kV) which yields ~4 kV DC after
    doubli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
2026-05-30 Promote Panasonic Service CD schematic to primary reference
    Adds the Panasonic Service CD schematic image (docs/reference/Panasonic_ServiceCD_Schematic.png)
    and reworks the reference hierarchy throughout the docs:
    1. docs/reference/Panasonic_ServiceCD_Schematic.png (NEW)
    2. docs/reference/Microwave_Oven_Inverter_HV_Power_Supply.pdf (VK3HZ)
    3. docs/reference/Panasonic_Inverter_Schematic_Annotated.pdf (Russian, demoted to supplementary)
    Updates throughout:
    docs/reference/README.md:
    - Reorders authoritative reference hierarchy
    - Documents component values from Panasonic schematic
    - Lists F6645M301GP-specific deltas from photos
    - Explicit list of Russian-schematic errors vs Panasonic schemati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
2026-05-30 Add bench observation: Frankenboard dry-run with no IGBTs
    Adds docs/bench_observations/ folder with first real bench data from the
    Frankenboard inverter under controlled conditions:
    - Mains 240V applied through 2A fuse
    - IGBTs unsoldered (on heatsink, not in circuit)
    - ESP32 sending command in force mode
    - Both scope channels battery-isolated
    - DS213 on Q701 gate-emitter, UT81B on CN701 pin 1
    Key findings:
    1. Inverter bias supply works correctly. R702 (3.5kΩ 15W) runs warm but
    stable, supplying the +20V gate driver rail.
    2. ASIC alive and responding to command. Gate drive signal at Q701
    pad confirms the controller is generating switching commands at
    correct voltage (26-28 Vpp).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
2026-05-31 Add failure analysis: pulse 500 mechanism that killed Q701
    Permanent record of exactly what the old firmware (commit 63e4eb7) did
    when 'pulse 500' was executed, and why this killed Q701 catastrophically
    while leaving Q702 untouched.
    The document analyzes the multi-phase sequence:
    Phase 1 (2000ms warmup at 35%):
    - GPIO4 commanding 222Hz at 35% duty
    - GPIO5 SIMULTANEOUSLY driving 110Hz onto pin 1 (inverter status output)
    - This corrupted the ASIC's own status feedback from the start
    Phase 2 (800ms ramp 35%->70%):
    - GPIO4 duty climbed continuously through 40 steps of 20ms each
    - GPIO5 still driving 110Hz, no signal disruption
    - ASIC's regulator chasing moving setpoint with corrup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
2026-05-31 Add post-mortem: Frankenboard Q701 failure #2 at 30% force mode
    Second catastrophic Q701 failure on the Frankenboard, this time under
    conditions that should have been safe per the previous post-mortem
    analysis.
    Test conditions:
    - New firmware (commit f468476) — VK3HZ-correct, no status corruption
    - Force mode at 30% duty (below VK3HZ P40 floor of 33%)
    - 240V split-phase via 2A fast-blow fuses, one per leg
    - IGBTs: Toshiba GT50J327 (Q701 original spec) + IHW30N120R5 (Q702 surviving)
    - Magnetron connected, FA/A/body wiring verified
    - All preliminary checks passed (zc, statusinfo, R702 bias warming normally)
    Outcome: Q701 catastrophically shorted within seconds of typing 'on'.
    Q702 still te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
2026-05-31 Correct failure history: Q702 also failed in the original donor event
    Previous version of the doc claimed 'Q702 has survived every failure event'
    which is wrong. The original donor-event failure that produced the
    Frankenboard killed BOTH Q701 AND Q702 — that's why both positions
    needed replacement IGBTs at the start of the project.
    The asymmetric pattern (Q701 dies, Q702 survives) is only accurate for
    the two post-replacement events:
    - May 2026 pulse 500 event (old firmware) — Q701 short, Q702 survived
    - 2026-05-30 force 30% event (new firmware) — Q701 short, Q702 survived
    Still informative — both replacement events showed the same asymmetry
    regardless of firmware version or drive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
2026-05-31 Add bring-up procedure for new factory boards
    Concrete protocol for testing the 3 new F6645M301GP factory boards
    arriving from AliExpress (Jun 01-07 estimated delivery).
    Procedure designed to answer the open question from today's Frankenboard
    post-mortem: was the failure board-specific contamination, or inherent
    to the dual-IGBT topology?
    Three stages:
    Stage 0 - Incoming inspection (no power):
    - Component value verification against Panasonic Service CD schematic
    - Photograph board revision markers (C701, C704/C705, R702)
    - Bench-trace half-bridge connectivity per board
    - Catch any anomalies before powering
    Stage 1 - Mains-only with NO IGBTs installed:
    - Apply 240V via 2A fuses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
2026-06-04 dual-IGBT fw: follow VK3HZ 230V duty table (75% P100)
2026-06-05 docs: session findings — official sources, warmup, drive/feedback, VK3HZ dual-IGBT fix
2026-06-05 fw: captured-profile playback (play) — exact 120V signal 85->87.5% @221.8Hz, GPIO5 read-only
2026-06-05 fw: fix dropped PIN_PWM definition
    [panasonic_dual_igbt_esp32s3.ino]
2026-06-05 tools: dual-channel DPC recorder — add 200us glitch filter, 30k buffer
    [dpc_recorder_esp32s3.ino]
2026-06-06 firmware: closed-loop status-gated startup (222Hz startup duty until 110Hz status, then run; cold-tube retry; idle-high status fix)
    [panasonic_dual_igbt_esp32s3.ino]
2026-06-06 firmware: status line is open-collector — INPUT_PULLUP provides the DPC's pull-up (wire inverter status direct to GPIO5, no divider)
2026-06-06 firmware: fix crash at run transition — start timer once, duty changes update sinkTicks only (no timer re-arm)
    [panasonic_dual_igbt_esp32s3.ino]
2026-06-06 fix(panasonic): correct CN701 pin labels in comments — pin1=STATUS, pin2=GND, pin3=PWM command
    Comments had command and status pins swapped throughout (header finding #1,
    divider note + ASCII, WIRING block, PIN_PWM/PIN_STATUS constexpr comments).
    Bench wiring was correct (board fires); only the documentation was wrong.
    Dropped unverified wire-color tags pending bench confirmation. No code change.
    [panasonic_dual_igbt_esp32s3.ino]
2026-06-07 VR701: shunt-fed current-sense gain trim; correct CT701 model
2026-06-07 firmware v6: thermal cutoff (NTC on GPIO8, 75C hard limit) + fan/tach (GPIO9/10) + fix strike detection (sustained-toggle, no more false RUN)
    [panasonic_dual_igbt_esp32s3.ino]
2026-06-07 web: add UTF-8 charset (fixes mangled chars), show heatsink in C and F
    [panasonic_dual_igbt_esp32s3.ino]
2026-06-07 firmware v9: kill false thermal trip on PLAY — 8-sample avg, ADC_11db attenuation, 500ms settle, 10 sustained reads, plausibility clamp
2026-06-12 docs: correct VR701/sense record — both in-repo schematics show CT701; shunt/R703 is later-board observation not schematic-backed; flag missing vr701_cal.py; promote wiper-trace as resolving measurem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
2026-06-14 mechanical: magnetron fan adapter, mount plate, launcher recess (2M246)
    - magtube_fan_adapter.scad: 60mm fan -> open face, 93x57 inner, 5mm collar-wrap
    skirt, flat fan collar
    - magtube_mount_plate.scad: 2M246 flange mirror (Meshy outline + dimensioned
    bore/relief/8-hole pattern)
    - launcher_magnetron_recess.scad: launcher-side negative (cutter + standalone
    mount) with gasket pocket + antenna bore
    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
    [launcher_magnetron_recess.scad, magtube_fan_adapter.scad, magtube_mount_plate.scad]
2026-06-17 docs: MAX31865 RTD bring-up blocked by defective hardware (2026-06-15)
    Full diagnostic post-mortem + 3 standalone test sketches. Firmware complete
    and verified at v17; failure isolated to bad MAX31865 boards + one bricked
    ESP32-S3. Records the CS-timing root-cause candidate, the resolution test
    (RTD-MANCS-v1), and the NTC fallback.
    [max31865_hwspi_test.ino, max31865_manualcs_test.ino, max31865_single_test.ino]
2026-06-17 dual_igbt v18: manual-CS SPI for MAX31865 (CS-gap fix) + full RTD integration
    Brings the v11-v17 RTD/dual-fan/Supermini work (never pushed) onto main and
    converts both RTD channels to bare-register manual-CS reads with an explicit
    CS-low->first-clock gap. Root cause of all prior garbage was the ESP32 SPI
    driver collapsing that gap so the MAX31865 never locked SPI mode. Bench-proven:
    comms round-trip OK, steady 109.7 ohm. CVD temperature math; default 2-wire.
    Doc updated: only one old board was actually dead, not the batch.
    [panasonic_dual_igbt_esp32s3.ino]
2026-06-18 docs: Heltec V3 gun-controller migration plan + open RTD/fan verification items
    Consolidates inverter controller + 915MHz LoRa node + status OLED onto one
    Heltec WiFi LoRa 32 V3. Documents the reserved-GPIO conflicts (6 pins collide
    with onboard LoRa/battery), a proposed remap onto free pins, OLED status page,
    and migration steps. Carries open items: 2nd RTD (heatsink), fan speed control,
    fan tach reporting, and pushing v19 (serial-status temps).
2026-06-18 dual_igbt v19: add live RTD temps (C and F, both sensors) to serial 'status'
2026-06-20 dual_igbt v25: RTD fault debounce + RPM clamp + fault counters + live mon stream
    - Debounce RTD faults (3 consecutive bad reads) so a single noisy SPI read no
    longer forces a fan to 100% — fixes random heatsink-fan full-speed surges.
    - Clamp impossible tach RPM (>8000) to 0 — kills phantom ~750k readings from a
    floating/noisy tach line picking up inverter switching edges.
    - Add per-sensor fault-event counters to status/mon for diagnostics.
    - Add continuous [mon] temp/fan stream (default 1s, 'mon <ms>') to replace the
    web UI lost to the Supermini FSPI/WiFi pin conflict.
    [panasonic_dual_igbt_esp32s3.ino]
2026-06-21 dual_igbt v25.3: fix hs fan tach garbage — move hs PWM off GPIO8 (onboard-LED pin)
    GPIO8 drives the Supermini's onboard LED; its dirty switching coupled into the
    hs tach line, producing a fixed ~378k-rpm phantom regardless of which tach pin
    was used (GPIO3 or GPIO44). Fan-swap test proved it was the channel, not the fan.
    Moved hs fan PWM GPIO8->GPIO43(TX) and hs tach GPIO3->GPIO44(RX), both clean
    UART0 pins (console is USB-CDC). Both fans now read real tach: mag ~3000rpm,
    hs ~4000rpm. RTD fault debounce + RPM clamp + raw-rpm diagnostic retained.
    [panasonic_dual_igbt_esp32s3.ino]
